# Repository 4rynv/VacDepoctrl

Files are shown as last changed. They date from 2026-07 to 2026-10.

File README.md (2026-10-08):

# VacDepoctrl — Vacuum Deposition Controller

A Raspberry Pi-based vacuum process controller. The current process is DC magnetron sputter deposition — chamber pump-down, argon gas flow, plasma ignition, and sputtering via a live Tkinter GUI with scrolling sensor graphs and a hardware-interlocked state machine. A thermal evaporation mode is planned as a second process on the same rig control stack.

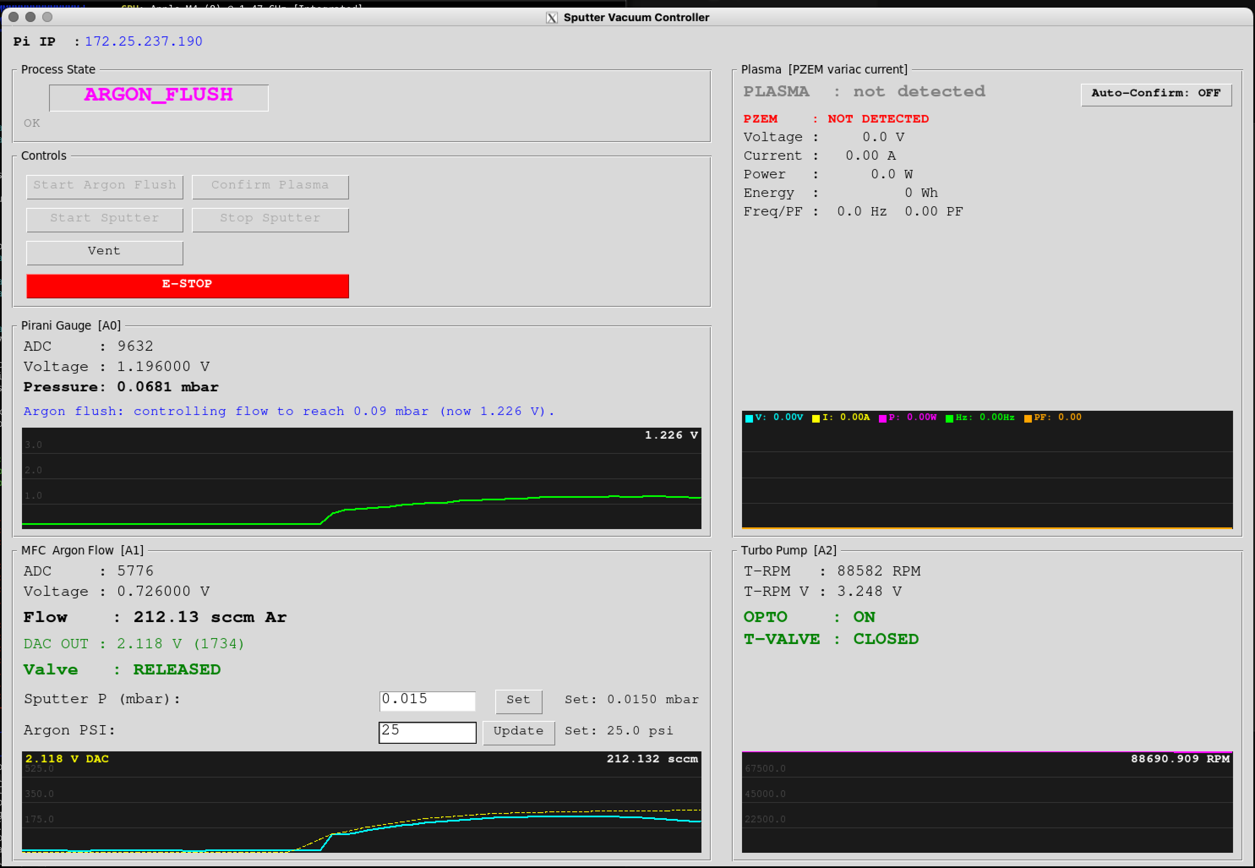
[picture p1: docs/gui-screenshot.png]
VacDepoctrl GUI


---

## Table of Contents

- [Hardware Overview](#hardware-overview)
- [Software Architecture](#software-architecture)
- [File Structure](#file-structure)
- [State Machine](#state-machine)
- [Pressure Reference](#pressure-reference)
- [Installation](#installation)
- [Running](#running)
- [Remote GUI Access](#remote-gui-access)
- [Web Dashboard](#web-dashboard)
- [Simulation Mode](#simulation-mode)
- [Configuration](#configuration)
- [GUI Guide](#gui-guide)
- [Known Limitations](#known-limitations)
- [Roadmap](#roadmap)

---

## Hardware Overview

| Component | Model | Interface | Notes |
|---|---|---|---|
| Microcontroller | Raspberry Pi 5 (BCM GPIO) | — | Host for all control logic |
| Pirani gauge | ACE Instruments DHPG-015 | Analog 0–10V | Divided to 0–3.3V before ADC (ratio 0.33) |
| ADC | ADS1115 | **I2C bus 1** @ 0x48 | Pirani on A0 (divided), MFC feedback on A1 (divided), turbo RPM tach on A2 |
| MFC | MKS 1179A | Analog 0–5V setpoint | 0–700 sccm Argon |
| DAC | MCP4725 | **I2C bus 1** @ 0x60 | Level-shifted to the MFC's full 0–5V setpoint range — see below |
| DAC buffer | LM358P op-amp | Analog | Buffers + level-shifts the DAC output up to 0–5V; DAC alone cannot drive the MFC setpoint input |
| Turbo enable | Opto-isolator (4N35) | GPIO 17 (BCM, phys 11) | Marginal — needs BC547 output buffer, see below |
| MFC valve close | Emergency shut | GPIO 27 (BCM, phys 13) | Pulls MFC valve closed on demand |
| Turbo inlet valve | Relay via BC547 | **GPIO 22 (BCM, phys 15)** | HIGH = valve OPEN, LOW = valve CLOSED (relay NC contact) |
| Energy meter | PZEM-004T-100A | Modbus-RTU over CP2102 USB-TTL, `/dev/ttyUSB0` | AC voltage/current/power on the variac output; plasma-ignition sensing. **Optional at startup** — see below |

### Raspberry Pi pin connections

[Full 40-pin header and device wiring diagram](docs/pinout.md)

| Function | BCM GPIO | Physical header pin | Connection |
|---|---|---|---|
| I2C1 SDA | GPIO2 | **3** | ADS1115 SDA + MCP4725 SDA |
| I2C1 SCL | GPIO3 | **5** | ADS1115 SCL + MCP4725 SCL |
| Signal ground | — | **6** (or another GND) | ADC/DAC signal ground |
| Turbo enable | GPIO17 | **11** | Opto-isolator input circuit |
| MFC emergency close | GPIO27 | **13** | Existing MFC valve-close interface |
| Turbo inlet valve | GPIO22 | **15** | BC547 relay-driver input |

GPIO23/24 (physical pins 16/18) are no longer the I2C connection.

### I2C: Hardware Bus 1 on GPIO 2/3

The Pi 5 uses hardware I2C1 at 100 kHz. Configure `/boot/firmware/config.txt`:

```ini
dtparam=i2c_arm=on
dtparam=i2c_arm_baudrate=100000
```

| Signal | BCM | Physical pin |
|---|---|---|
| SDA | GPIO 2 | 3 |
| SCL | GPIO 3 | 5 |
| GND | Ground | 6 |

Connect both ADS1115 and MCP4725 to this bus; keep pull-ups at 3.3 V.
Power down before moving SDA/SCL from the previous GPIO23/24 wiring.
The code uses `ExtendedI2C(I2C_BUS_NUMBER)` with `I2C_BUS_NUMBER = 1`.
The older software-bus setup was a workaround for reported damaged GPIO2/3
on a previous setup; this configuration assumes functioning GPIO2/3.
Reboot after changing boot configuration; the operator performs device checks
and the first controller launch with equipment in a safe condition.

### Voltage Divider (Pirani Output)

The DHPG-015 outputs 0–10V. A 3-resistor voltage divider scales this to 0–3.3V for the ADS1115 (divider ratio 0.33). All pressure thresholds in `config.py` are expressed in post-divider (ADC-side) volts. The full manufacturer calibration table lives in `hardware/datasheets/Di-Hi-Pr-Pirani output voltage.pdf` and is transcribed as `_PIRANI_CAL` in `main.py`.

### DAC Output Buffer + Level Shifter (LM358P)

The MCP4725 cannot source enough current to drive the MFC setpoint input directly — above ~1.25V the output voltage collapses under load even though it reads correctly when unloaded. An LM358P stage buffers the DAC output and shifts it up to the MFC's full 0–5V setpoint range before it reaches the MFC (`ARGON_DAC_VREF = 5.0` in `config.py` reflects this — commanded flow covers the full 0–`MFC_FULL_SCALE` range, not a fraction of it):

```
DAC OUT ──────────────┬──── LM358 IN+ (pin 3)
                       │
                  (feedback) IN- (pin 2) ──── OUT (pin 1) ──── MFC setpoint
LM358 VCC (pin 8) ── Pi 5V
LM358 GND (pin 4) ── GND
```

Power the op-amp from the Pi's **5V** rail, not 3.3V. The diagram above shows the original current-buffer wiring; the gain-setting feedback network that shifts the output up to 0–5V isn't captured in this ASCII diagram.

### Turbo Inlet Valve (GPIO 22 → BC547 → Relay → Solenoid)

The turbo inlet solenoid valve (~50 mA @ 25–26 V) is switched by a relay, driven by a BC547:

```
GPIO22 ──470Ω── base   BC547   collector ── relay coil ── +5V
                          emitter ── GND         ▲
                                          1N4007 across coil
                                          (band toward +5V)

Valve circuit ── relay COM + NC contacts (isolated from the Pi)
```

- Valve is wired through the relay's **NC (normally closed)** contact: relay released = valve circuit shorted = **valve CLOSED**; relay energized = **valve OPEN**.
- Logic (in `_poll()`, `turbo_valve_step()`): valve held CLOSED at all times; **latched OPEN** during **VENTING** once turbo pump RPM (tach on ADC A2, see [Turbo Pump RPM](#turbo-pump-rpm-adc-a2)) sustains `TURBO_VALVE_CONFIRM_SAMPLES` consecutive reads at or below `TURBO_VALVE_OPEN_RPM_MAX` (35000 RPM); re-closed automatically on leaving VENTING. The debounce prevents a single corrupted I2C read from opening the valve; the latch prevents relay chatter once open. Driven by rotor speed directly rather than inferring it from chamber pressure — the earlier pressure-based gate (`TURBO_VALVE_OPEN_MBAR`) has been replaced.
- Fail-safe: if the Pi crashes or loses power, the relay releases and the valve **fails closed** — the safe direction for the turbo inlet.
- GUI shows live actuation state (`T-VALVE : CLOSED` / `OPEN (venting)`).

### Turbo Pump RPM (ADC A2)

- Tach/speed output, 0–3.3V linear = 0–90000 RPM (`TURBO_RPM_VOLTAGE_FULL_SCALE`, `TURBO_RPM_FULL_SCALE`), read by `TurboRPMController` (`turbo_rpm.py`) every poll tick regardless of state.
- Displayed in its own **Turbo Pump** panel (`T-RPM`, `T-RPM V`, a scrolling RPM graph, plus `OPTO` and `T-VALVE` state — both turbo-side actuators, moved here from the Pirani panel) — below the Plasma panel, beside the Pirani/MFC panels.
- During **VENTING**, once RPM drops to/below `VENTING_PUMP_OFF_PROMPT_RPM` (2000), the Pirani panel's status message turns orange and prompts the operator to turn off the primary/roughing pump — an early, informational cue, not a gate. The actual gate on completing the vent is separate — see [Vent Completion Confirmation](#vent-completion-confirmation) below.
- Feeds the turbo inlet valve interlock above and the cross-sensor checks below.

### Vent Completion Confirmation

Reaching atmospheric pressure during VENTING does **not** by itself complete the vent. Earlier, `sm.update()` transitioned `VENTING → IDLE` purely from Pirani voltage — but the turbo inlet valve closes the instant the state leaves VENTING (`turbo_valve_step()`), so that auto-transition could reclose the valve before the operator had any real chance to react to the "turn off the primary pump" cue above, let alone actually do it.

`VENTING → IDLE` is now owned exclusively by `_poll()` (the same ownership pattern as `ARGON_FLUSH → PLASMA_IGNITING`), gated by `vent_complete_ready()`: **both** atmospheric pressure **and** an explicit operator click are required.

- Once Pirani reaches `VENTING_COMPLETE_VOLTAGE` during VENTING, `_state["vent_complete_pending"]` latches True — the Pirani panel's status message turns red ("Atmosphere reached — turn OFF the primary/roughing pump, then click Confirm Pump Off") and a **Confirm Pump Off** button appears in Controls (hidden otherwise, same show/hide pattern as Clear Fault).
- Clicking it sets `_state["vent_complete_confirmed"]`; `_poll()` picks this up on its next tick and, if pressure is still at/above atmosphere, transitions to IDLE — closing the turbo inlet valve as part of the normal VENTING-exit path.
- Both flags reset on entering IDLE or VENTING (`handle_hardware_interlocks()`), so a stale confirmation from a previous cycle can never auto-complete the next one.

### Energy Meter (PZEM-004T-100A, plasma ignition sensing)

Reads AC voltage/current/power/energy/frequency/power-factor on the sputtering supply's **variac output** and uses the current-draw step when the discharge strikes to detect plasma ignition. Talks Modbus-RTU over a CP2102 USB-TTL adapter plugged into the Pi's USB port (`pzem_meter.py`) — a completely separate transport from the ADS1115/MCP4725 I2C bus above.

> [!warning] Mains AC hazard
> The PZEM's voltage-sense terminals and current-transformer (CT) clamp are on **live mains-derived AC**, not the Pi's low-voltage side. Work de-energized (variac and upstream breaker off), verify with a meter before touching any terminal, don't work alone, and don't exceed the CT's 100A rating. The PZEM's internal isolation protects the TTL/USB side from the AC side *once wired correctly* — it does not protect you while wiring it.

#### Wiring

**AC side (mains, de-energized while wiring):**

- Connect the PZEM's **L / N voltage-sense terminals directly across the variac's OUTPUT** (not its input) — the two wires feeding whatever the variac drives (typically an HV/isolation transformer feeding the sputtering cathode supply).
- Clamp the **split-core CT around the same variac output's live (L) conductor** — do not clamp both L and N together (their fields cancel and it reads ~0A), and do not clamp the input side.
- Wiring the CT and voltage sense to the *same* side (output) is required for the power reading to mean anything — the PZEM computes P = V × I × PF locally, so V and I must reflect the same node.
- This placement means voltage/current/power all read what's actually delivered to the sputtering supply, independent of the variac's own tap position — exactly the load signature that changes when the discharge strikes (impedance drop → current step).

**TTL side (isolated, low-voltage, safe to wire live):**

| PZEM TTL pin | CP2102 pin | Notes |
|---|---|---|
| 5V  | 5V  | PZEM-004T v3.0's TTL interface requires 5V — verify the CP2102's voltage-select jumper (if it has one) is set to 5V, not 3.3V |
| GND | GND | Common ground |
| TXD | RXD | Cross — PZEM transmits into the adapter's receive pin |
| RXD | TXD | Cross — PZEM receives from the adapter's transmit pin |

Plug the CP2102 into any Pi USB port. It enumerates as `/dev/ttyUSB0` (check with `ls /dev/ttyUSB*`; use a `/dev/serial/by-id/...` symlink instead if more than one USB-serial device is ever attached). The Pi user needs the `dialout` group to access it without root:

```bash
sudo usermod -a -G dialout $USER
# log out and back in for the group change to take effect
```

#### Protocol

Modbus-RTU, 9600 baud 8N1, factory-default slave address `0xF8`. `pzem_meter.py` hand-rolls the request framing and CRC16 (matching how `mfc_control.py` hand-rolls the MCP4725 I2C write) rather than pulling in a general Modbus library — reads input registers 0x0000–0x0009 (voltage, current, power, energy, frequency, power factor, alarm) every poll tick.

**Optional hardware, unlike the ADS1115/MCP4725 checked in `_startup_self_test()`:** this sensor may not be wired up yet. `PZEMController.read()` never raises — if the serial port can't be opened or the meter doesn't respond, it returns `ready=False` and a zeroed reading. `main.py`'s two PZEM cross-sensor checks (below) only evaluate `if e["ready"]`, so nothing they do can fire until the meter is actually installed and responding — deploying this code cannot regress a rig that doesn't have the PZEM wired yet.

#### Plasma Detection

`plasma_detect_step()` applies the same debounced ON/OFF hysteresis pattern as the turbo enable opto (`TURBOOPTO_ON/OFF_THRESHOLD`) to the PZEM's current reading: `PZEM_PLASMA_CURRENT_ON_A` (default 1.0A, **unvalidated placeholder**) held for `PZEM_PLASMA_CONFIRM_SAMPLES` (3) consecutive ticks latches `plasma_detected` True; it clears immediately below `PZEM_PLASMA_CURRENT_OFF_A` (0.6A). Like every other cross-sensor threshold in this repo, these must be bench-measured against the real supply's no-load vs. struck-plasma current before they mean anything.

`plasma_detected` drives the **Plasma** GUI panel (replacing the old placeholder) and the `PLASMA_IGNITING → SPUTTER_READY` confirmation, which now has three paths:

| Path | Trigger | Default |
|---|---|---|
| Manual | Operator clicks **Confirm Plasma** | Always available |
| Hybrid cue | Confirm Plasma button highlights green once `plasma_detected` is True during `PLASMA_IGNITING` — operator still clicks | Always on |
| Auto-confirm | Operator arms the **Auto-Confirm** toggle in the Plasma panel; while armed, a confirmed detection advances the state machine the same way a manual click would, via the same `_complete_plasma_confirmation()` path | **Off by default** |

Auto-confirm is an explicit operator opt-in, not the default, because `PZEM_PLASMA_CURRENT_ON_A` is unvalidated — the same reasoning as every other "unvalidated until confirmed on the bench" threshold in `config.py`. `PLASMA_IGNITING`'s own `PLASMA_IGNITION_TIMEOUT` abort-to-READY path is unchanged and still the fallback if neither manual nor auto-confirm fires.

#### Bring-up notes / troubleshooting

- **Board-specific terminal layout, not the generic datasheet.** On Aryan's board, the AC-side 4-terminal block is L / N (voltage sense, across variac output) and two CT-lead terminals — but the *position* of these on the physical block didn't match the generic PZEM-004T datasheet. The L line initially went to the board's 10A direct-pass-through terminal position instead of the 100A/CT-clamp position; moving it to the correct terminal (found via the board's own silkscreen, not the datasheet) fixed it. **Always read your specific board's silkscreen, not a generic online diagram.**
- **The PZEM's measurement MCU is powered from the AC L/N line itself**, not the TTL 5V header. Symptom if you wire TTL first and haven't energized L/N yet: CP2102 TX blinks (host is sending fine), PZEM never replies — looks like a dead unit but is just unpowered. Resolves once L/N is actually connected to live AC.
- **A struck-but-undetected plasma likely means the CT isn't sensing the load, not a threshold-tuning problem.** Hit 2026-07-12: operator visually confirmed plasma and clicked Confirm Plasma, `PLASMA_IGNITING → SPUTTER_READY` succeeded, then `pzem_plasma_absent_check()` force-shut-down 5s later with the PZEM reporting **0.00 A** the entire time. A true zero (not "some current below 1.0A") points at the sensor path, not calibration — most likely the CT clamp isn't actually installed on the load line yet (this repo's CT bring-up was still pending a bench test on the real variac-output load as of the prior session), or is clamped over both L and N together (fields cancel to ~0A), rather than L alone.
- **If real current draw is small relative to the CT's 100A rating, wind multiple turns of the live conductor through the clamp before closing it.** A CT senses ampere-*turns*, so *N* turns gives `N × I_actual` on the reading — useful because a 100A-rated core sensing a sub-1A sputtering load sits at the very bottom of its response curve, where accuracy/noise floor issues are common. Divide the reported current/power by *N* in software to recover the true value, or (simpler, since only the comparison matters) scale `PZEM_PLASMA_CURRENT_ON_A`/`_OFF_A` by *N* instead. Sanity-check the real current independently first (a separate clamp meter, or the sputtering supply's own front-panel readout) before deciding how many turns to use.

### Cross-Sensor Consistency Checks

Every threshold elsewhere in this doc compares one sensor to one fixed value. These instead compare two live readings to each other — catching a case where each reading is individually "in range" but the two together don't make physical sense. All feed the **global safety gate** below: a sustained flag forces a full hardware cutoff, not just a status message. Grace periods are placeholder defaults (favor fewer false positives over noise from normal settling time) — tune once measured against real spin-up/response/settling behavior on the bench. Because a false positive forces a real shutdown, treat these as unvalidated until confirmed on the bench.

| Check | Compares | Flags when | Config |
|---|---|---|---|
| `turbo_spinup_check()` | Turbo enable opto (GPIO 17) vs turbo RPM (ADC A2) | Opto commanding the turbo on for `TURBO_SPINUP_GRACE_SECONDS` (60s) while RPM stays below `TURBO_RPM_STALL_THRESHOLD` (10000) — turbo/RPM-sensor/wiring fault, or the turbo never spun up at all | `config.py` |
| `turbo_rpm_drop_check()` | Same opto/RPM pair, but tracks a confirmed-healthy peak | RPM has exceeded `TURBO_RPM_STALL_THRESHOLD` at least once (confirmed healthy spin), then drops back below it for `TURBO_RPM_DROP_GRACE_SECONDS` (10s) while opto is still on — a running turbo failing/degrading, distinct from "never spun up" | `config.py` |
| `mfc_flow_check()` | Commanded flow (DAC/`flow_target`) vs measured flow (A1 feedback) | Commanded ≥ `MFC_FLOW_MIN_COMMANDED_SCCM` (20) but measured stays below `MFC_FLOW_RESPONSE_FRACTION` (0.2×) of commanded for `MFC_FLOW_GRACE_SECONDS` (5s) — MFC not responding, dead unit, or empty gas supply | `config.py` |
| `dac_saturation_flow_check()` | DAC output voltage vs measured flow | DAC pegged within `DAC_SATURATION_MARGIN_V` (0.1V) of `ARGON_DAC_VREF` while measured flow stays below `DAC_SATURATION_FLOW_FRACTION` (0.5×) of `MFC_FULL_SCALE`, for `DAC_SATURATION_GRACE_SECONDS` (10s) — the PID has given up on proportional correction and is commanding max output with nothing coming back: stuck valve, blocked line, or empty supply. A stronger signal than `mfc_flow_check` alone | `config.py` |
| `pressure_convergence_check()` | Current Pirani voltage vs the active PID target (flush/sputter) | `\|current - target\|` exceeds `PRESSURE_CONVERGENCE_TOLERANCE_V` (0.3V) for `PRESSURE_CONVERGENCE_GRACE_SECONDS` (90s) despite the control loop running — leak, stuck valve, or MFC fault. Raised from 20s after a bench run showed a legitimate large setpoint step (e.g. PLASMA_IGNITING → SPUTTER_READY) needs longer than that to converge given the deliberately gentle PID tuning | `config.py` |
| `pzem_plasma_absent_check()` | Process state (SPUTTER_READY/SPUTTERING only) vs PZEM `plasma_detected` | In SPUTTER_READY or SPUTTERING — both assume plasma is already lit — with no PZEM-confirmed current draw for `PZEM_PLASMA_ABSENT_GRACE_SECONDS` (5s): an arc dropout or the plasma extinguishing mid-run. PLASMA_IGNITING is deliberately excluded (`PLASMA_IGNITION_TIMEOUT` already owns "never struck"). Only evaluated once the PZEM is `ready` — see Energy Meter section above | `config.py` |
| `pzem_power_unexpected_check()` | Process state (everywhere except PLASMA_IGNITING/SPUTTER_READY/SPUTTERING) vs PZEM `plasma_detected` | Plasma-level current draw while nowhere near attempting ignition (IDLE/PUMP_DOWN/READY/ARGON_FLUSH/VENTING) for `PZEM_POWER_UNEXPECTED_GRACE_SECONDS` (5s) — stuck relay, live supply, or wiring fault. Only evaluated once the PZEM is `ready` | `config.py` |

All are pure functions (`main.py`, next to `turbo_valve_step()`) — no I/O, no wall-clock access internally (the current timestamp is passed in), so they're tested directly like the calibration/valve logic.

### Global Safety Gate

Everything above this point in the doc is a *local* mechanism: a specific check for a specific failure, conditioned on which state you're in. The global gate is different — evaluated every poll tick **regardless of current state**, and any single condition tripping it forces the exact same full cutoff: turbo valve closed (direct GPIO write), MFC flow/valve/opto off, state forced to IDLE (`sm.emergency_stop()`), **and the trip latches** (see below).

| Condition | Detects | Config |
|---|---|---|
| Sustained cross-sensor flag | Any of the checks above, once their own grace period elapses | see table above |
| `sensor_range_check()` | Any ADC-derived voltage (Pirani, MFC feedback, turbo tach) outside `SANE_VOLTAGE_MIN`/`SANE_VOLTAGE_MAX` for `SENSOR_RANGE_CONFIRM_SAMPLES` (5) consecutive ticks — disconnected, shorted, or miswired sensor, not a legitimate reading at any pressure/flow/speed. Suppressed for `STARTUP_GRACE_SECONDS` (5s) after the poll loop starts — real analog settling transients (MFC feedback observed at -0.15 to -0.23V for a few seconds after power-on) tripped this otherwise | `config.py` |
| Consecutive poll-loop exceptions | `CONSECUTIVE_EXCEPTION_LIMIT` (5) ticks in a row raise — occasional I2C/EMI glitches are tolerated (as before), but this many in a row is a real fault, not noise. Also suppressed during `STARTUP_GRACE_SECONDS` | `config.py` |
| Heartbeat / watchdog | The GUI thread (`_refresh()`) checks `_state["last_tick"]`; if the poll loop hasn't updated it within `HEARTBEAT_TIMEOUT_SECONDS` (2.0s), the poll thread is presumed stalled/hung. Checked from the GUI thread specifically — a hung poll thread can't detect its own hang | `config.py` |

All of this routes through `_force_safe_shutdown(reason)` (`main.py`) — safe to call every tick for as long as a condition persists (GPIO/state-machine calls are idempotent; `_set_error()` de-dupes the repeated log line rather than spamming it). `handle_hardware_interlocks()`'s own mfc/pirani cutoffs are already exception-safe (`SputterStateMachine` catches callback errors internally), so the only extra guarding needed is around the direct turbo-valve GPIO write, in case the poll thread hung mid-I2C-transaction.

**The trip latches — a bench run found why this matters.** `emergency_stop()` alone forces IDLE, but IDLE's own auto-resume-to-PUMP_DOWN logic (`_poll()`) will immediately re-enter PUMP_DOWN if pressure is already low (e.g. an external roughing pump already has the chamber down) — silently undoing the shutdown within one tick, with the process continuing as if nothing happened. `_force_safe_shutdown()` now sets `_state["safety_tripped"]`, which blocks that auto-resume and shows a red banner + "Clear Fault" button in the Process State panel, plus a one-time modal alert. The IDLE branch checks this flag before its auto-transition. Clearing does **not** reset the underlying check's own "since" timer — if the root cause is still present, it re-trips immediately on the next tick. That's intentional: acknowledging a fault without fixing it must not let the process quietly continue.

### Startup Self-Test

Runs once before the poll thread starts (`_startup_self_test()`, `main.py`): re-validates config invariants at runtime (`config_sanity_failures()` — same checks as `TestConfigSanity`, but live, so a bad future edit to `config.py` is caught before the app runs with a broken safety threshold; this is exactly the class of bug that shipped once, `VENTING_COMPLETE_VOLTAGE` at ~5 mbar instead of near-atmosphere), and confirms the ADS1115 and MCP4725 DAC actually ACK on the I2C bus. Any failure prints to console and exits — no GUI exists yet at this point in startup.

### Persistent Event Log

Every operator-visible error/warning and every state transition is appended to `sputter_ctrl.log` (next to `main.py`, `EVENT_LOG_FILENAME` in config) via `_log_event()` — the GUI status bar only shows the latest message and auto-expires it after `ERROR_DISPLAY_SECONDS`, so this is the only place an incident can be reconstructed after the fact. `_set_error()` is the single choke point every error message goes through (writes `_state["error"]` and logs, de-duping repeats); `handle_hardware_interlocks()` logs every transition unconditionally, regardless of which state it's entering.

Do **not** drive relay coils or solenoids from a 4N35 directly — see the hard-won rule below.

### Opto/Load Rule of Thumb (learned the expensive way)

A 4N35's usable output current is roughly `CTR (~100%) × LED current (~10 mA max from a GPIO)` ≈ **10 mA**. Asked for more, it goes linear and drops the supply across itself (looks like a mystery series resistor). Loads measured on this rig:

| Load | Draw | 4N35 alone? |
|---|---|---|
| Turbo enable input | ~15–30 mA | **No** — needs BC547 buffer (pending) |
| Relay coil (5V) | ~60 mA | No — driven by BC547 directly, opto not needed (relay contacts provide the isolation) |
| Inlet solenoid | ~50 mA @ 26V | No — relay contacts switch it |

The turbo enable opto (GPIO 17) currently only works with excess LED drive; the proper fix is a BC547 buffer on its output (opto pin 5 → enable+, pin 4 → BC547 base, 10 kΩ base–emitter, BC547 C/E across the enable terminals). Flyback diodes go **in parallel across coils** (reverse-biased), never in series.

---

## Software Architecture

```
main.py
├── Hardware init (GPIO, ExtendedI2C bus 1, ADS1115)
├── Shared state dict (thread-safe, _lock)
├── Polling thread (_poll) — runs every POLLING_INTERVAL (0.2s)
│   ├── Reads Pirani + MFC + turbo RPM (A2) + PZEM (variac current) sensors
│   ├── Drives MFC pressure PID loop
│   ├── Drives turbo inlet valve latch (GPIO 22), gated on turbo RPM (not pressure)
│   ├── Debounced plasma_detect_step() from PZEM current -> plasma_detected
│   ├── Auto-confirms PLASMA_IGNITING -> SPUTTER_READY if the operator has
│   │   armed Auto-Confirm and plasma_detected is True
│   ├── Calls sm.update() for auto-transitions
│   ├── Converts Pirani voltage <-> mbar via log-linear calibration table
│   ├── End-of-tick safety cutoff re-assert (E-STOP race guard)
│   └── Updates shared state dict
├── Tkinter GUI (main thread)
│   ├── _refresh() — runs every GUI_REFRESH_INTERVAL (200ms) via root.after()
│   ├── Scrolling graphs (ScrollingGraph)
│   ├── Live pressure readout in mbar (adc_voltage_to_mbar)
│   ├── Manual set-point entry fields (sputter target mbar, argon PSI)
│   ├── Error display with ERROR_DISPLAY_SECONDS auto-expiry
│   └── Button callbacks → shared _try_*() operator commands
├── Web dashboard server (daemon threads — web_ui.py, see Web Dashboard)
│   ├── GET /events — SSE stream of _state snapshots to each browser
│   └── POST /command — dispatches the SAME _try_*() operator commands
└── Hardware interlock callback
    └── handle_hardware_interlocks() — fires on every state transition
```

The polling thread and GUI thread never share objects directly — all data passes through `_state` dict protected by `_lock`. On window close, `_stop_event` is set and the polling thread is **joined** (2 s timeout) before hardware shutdown and `GPIO.cleanup()`.

**E-STOP race guard:** the poll loop reads the state once per tick; if an E-STOP/vent transition lands mid-tick, the interlock callback's cutoff could be overwritten by in-flight `valve_release()`/`set_flow()` calls. The poll loop therefore re-asserts the full safety cutoff at the end of any tick in which the state machine moved to IDLE/VENTING — the cutoff is always the last hardware write of the tick.

**Error handling:** errors are no longer cleared by the polling loop each tick. They persist in the status bar for `ERROR_DISPLAY_SECONDS` (10 s) and then auto-expire, so both operator-guard messages and the plasma-timeout message are actually readable.

---

## File Structure

```
VacDepoctrl/
├── main.py            — Entry point: GUI, polling thread, hardware init, cal table
├── config.py          — All constants, thresholds, and pin assignments
├── state_machine.py   — SputterStateMachine class (future: per-process state machines)
├── drivers/           — one class per hardware device
│   ├── mfc_control.py — MFCController class (DAC, valve, PID loop)
│   ├── pirani.py      — PiraniController class (ADC, turbo enable opto)
│   ├── turbo_rpm.py   — TurboRPMController class (ADC A2 tach → RPM)
│   └── pzem_meter.py  — PZEMController class (PZEM-004T-100A, Modbus-RTU over USB-TTL)
├── ui/
│   ├── graph.py       — ScrollingGraph class (pure Tkinter, no matplotlib; single/dual/multi-series)
│   ├── web_ui.py      — browser dashboard server (stdlib HTTP + SSE), parallel to the Tkinter GUI
│   └── web/
│       └── index.html — the dashboard page (self-contained: inline CSS/JS, no CDN)
├── sim/
│   └── sim_hardware.py — ChamberSim + fake hardware modules for SPUTTER_SIM=1 (Simulation Mode)
├── hardware/
│   ├── Raspi_HAT/     — KiCad project for the custom Raspberry Pi HAT (schematic/PCB/BOM)
│   └── datasheets/    — Pirani gauge output-voltage table PDF
├── docs/              — GUI screenshot and other README assets
├── assets/            — desktop/app icon source (app-icon*.png, AppIcon.icns)
├── scripts/
│   ├── setup.sh       — venv + dependency installer, also installs the desktop launcher
│   ├── VacDepoctrl.desktop       — desktop launcher icon (installed by setup.sh; see Installation)
│   ├── setup_remote_gui_macos.sh — one-time XQuartz setup, see Remote GUI Access
│   └── build_mac_launchers.sh    — builds the VacDep Remote.app / VacDep Simulation.app Desktop icons
└── tests/
    ├── adc_test.py         — ADS1115 read loop (bus 1)
    ├── dac_test.py         — MCP4725 sweep + readback (bus 1)
    ├── opto_test.py        — GPIO 17 turbo enable opto toggle
    ├── turbo_valve_test.py — GPIO 22 relay/valve toggle
    ├── pzem_test.py        — PZEM-004T-100A live reading loop (USB-TTL)
    └── unit/               — hardware-free unit suite (fakes.py + test_all.py)
```

---

## State Machine

### States and Transitions

```
                    pressure rises
         ┌─────────────────────────────┐
         ▼                             │
       IDLE ──(pressure drops)──► PUMP_DOWN ──(vacuum reached + opto)──► READY
         ▲                             │                                     │
         │                    pressure rises                        [Start Argon Flush]
         │                             │                                     ▼
         └─────────────────────────────┘                            ARGON_FLUSH
                                                                         │
                                                              (0.09 mbar reached)
                                                                         ▼
                                                               PLASMA_IGNITING
                                                              │              │
                                                   [Confirm Plasma]    (2 min timeout)
                                                              │              │
                                                              ▼              ▼
                                                        SPUTTER_READY     READY
                                                              │
                                                       [Start Sputter]
                                                              ▼
                                                          SPUTTERING
                                                              │
                                                       [Stop Sputter]
                                                              ▼
                                                          VENTING
                                                              │
                                                (3.0V atmosphere) + [Confirm Pump Off]
                                                              ▼
                                                            IDLE

         Any state ──[Vent]──► VENTING ──(3.0V Pirani + Confirm Pump Off)──► IDLE
         Any state ──[E-STOP]──► IDLE (immediate hardware cutoff, latched — Clear Fault to resume)
```

### Automatic Transitions

| From | To | Condition | Where |
|---|---|---|---|
| `IDLE` | `PUMP_DOWN` | Pirani voltage ≤ 2.71V (10 mbar) | `_poll()` |
| `PUMP_DOWN` | `IDLE` | Pirani voltage ≥ 2.71V (pump failure/leak) | `_poll()` + `sm.update()` |
| `PUMP_DOWN` | `READY` | Voltage ≤ 0.3V AND opto enabled | `sm.update()` |
| `READY` | `PUMP_DOWN` | Pirani voltage ≥ 2.71V (pressure degraded) | `sm.update()` |
| `ARGON_FLUSH` | `PLASMA_IGNITING` | Voltage ≥ 1.287V (0.09 mbar) | **`_poll()` only** — sole owner: arms the ignition timeout and fires `_ignite_plasma()` |
| `PLASMA_IGNITING` | `READY` | 120s timeout, no plasma confirmation | `_poll()` |
| `PLASMA_IGNITING` | `SPUTTER_READY` | PZEM confirms plasma-level current draw, **only if the operator has armed Auto-Confirm** | `_poll()` — see [Energy Meter](#energy-meter-pzem-004t-100a-plasma-ignition-sensing) |
| `VENTING` | `IDLE` | Pirani voltage ≥ 3.0V (near-atmosphere) **AND** operator has clicked Confirm Pump Off | **`_poll()` only** — see [Vent Completion Confirmation](#vent-completion-confirmation) |

`PLASMA_IGNITING → SPUTTER_READY` is **operator-driven by default** (Confirm Plasma button, highlighted once the PZEM confirms detection) with an explicit opt-in **Auto-Confirm** toggle for the sensor-driven path — see the Energy Meter section for why auto-confirm defaults off. `VENTING → IDLE` similarly requires an explicit operator click regardless of pressure — there is no auto-confirm option for this one, since it's gating a real physical action (turning off the primary pump), not just a detection threshold.

### Manual Transitions (Operator Buttons)

| Button | Transition | Guard |
|---|---|---|
| Start Argon Flush | `READY → ARGON_FLUSH` | Argon inlet ≥ 15 psi |
| Confirm Plasma | `PLASMA_IGNITING → SPUTTER_READY` | None |
| Start Sputter | `SPUTTER_READY → SPUTTERING` | Argon inlet ≥ 15 psi |
| Stop Sputter | `SPUTTERING → VENTING` | None |
| Vent | `PUMP_DOWN`, `READY`, `ARGON_FLUSH`, `PLASMA_IGNITING`, `SPUTTER_READY`, `SPUTTERING` → `VENTING` | None — `PUMP_DOWN` added 2026-07-12 (previously only `IDLE→PUMP_DOWN→IDLE` was reachable from PUMP_DOWN; vent is now available mid-pump-down too) |
| Confirm Pump Off | `VENTING → IDLE` | Only appears once atmosphere is reached; see [Vent Completion Confirmation](#vent-completion-confirmation) |
| E-STOP | Any → `IDLE` | None — immediate. Routes through `_force_safe_shutdown()`: closes the turbo valve by direct GPIO write (no dependency on the poll thread being alive) and **latches** — Clear Fault required to resume, like a real EMO reset |

### Hardware Interlock Callback

`handle_hardware_interlocks()` fires synchronously on every state transition:

- **→ IDLE or VENTING**: `mfc.set_flow(0)`, `mfc.valve_close()`, `pirani.set_opto(False)`, and resets `plasma_ignition_start` / `plasma_ignition_triggered` so the next flush cycle starts clean (a stale flag previously could leave PLASMA_IGNITING with no armed timeout)
- **→ PUMP_DOWN**: `pirani.set_opto(False)` — resets opto for next pump-down cycle

During VENTING the poll loop additionally holds the MFC valve **closed** every tick (venting is done with the turbo inlet valve, not through the MFC).

---

## Pressure Reference

All voltages are post-divider (ADC input, ×0.33 from raw gauge output). Conversion between Pirani voltage and mbar uses **log-linear interpolation** against the full manufacturer calibration table (`_PIRANI_CAL` in `main.py`, source PDF in `hardware/datasheets/`): linear in voltage, logarithmic in pressure, matching the gauge's thermal-conductivity response. Both directions are implemented (`mbar_to_adc_voltage`, `adc_voltage_to_mbar`) and round-trip to machine precision at all 51 table points.

| Pressure (mbar) | Raw gauge (V) | ADC input (V) | Significance |
|---|---|---|---|
| 999 | 10.00 | 3.30 | Atmosphere (ADC saturated) |
| ~213 | — | 3.0 | `VENTING_COMPLETE_VOLTAGE` — VENTING → IDLE (safety margin below the 3.30V atmosphere point so the transition reliably fires) |
| 10 | 8.20 | 2.706 | `IDLE_PRESSURE_MAX_VOLTAGE` — pump-down gate |
| 0.09 | 3.90 | 1.287 | `ARGON_FLUSH_TARGET_VOLTAGE` — plasma ignition pressure |
| ~0.183 | 4.24 | 1.4 | Turbo enable opto fires (PUMP_DOWN, transition-based; raised from 1.3V 2026-07-12) |
| ~0.0057 | 0.91 | 0.3 | `PUMP_DOWN_COMPLETE_VOLTAGE` — PUMP_DOWN → READY gate (raised from 0.2V 2026-07-12) |
| 0.007 | 1.10 | 0.363 | 0.007 mbar — default sputtering pressure |

The GUI displays live pressure in mbar (bold, under the voltage readout), computed via `adc_voltage_to_mbar()`; reads `ATM (>999 mbar)` at ADC saturation.

### Sputter Target Pressure (operator-settable)

An input field sets the SPUTTER_READY / SPUTTERING target pressure directly in mbar (default 0.007). Entered values are converted to an ADC voltage target via the calibration table before being passed to `pressure_control_step()`.

Validated at entry: must be `> 0` and `≤ SPUTTER_TARGET_MAX_MBAR` (0.05 mbar). Values above the cap are rejected with a warning dialog rather than silently accepted — this also catches an Argon PSI value (tens) fat-fingered into this field, since any such value is far above the cap. Similarly, the Argon PSI field rejects anything below `ARGON_PRESSURE_MIN_PSI` (15 psi) with a warning, catching a Sputter P mbar value entered in the wrong field.

### Turbo Enable Opto Logic (GPIO 17)

Transition-based, not level-based:

- Goes **HIGH** the first time Pirani voltage drops below **1.4V** during `PUMP_DOWN` (raised from 1.3V 2026-07-12)
- Once set, stays HIGH until any state transition resets it via the interlock callback
- This prevents opto chatter on noisy ADC readings near the threshold
- Separate from `TURBOOPTO_ON_THRESHOLD`/`TURBOOPTO_OFF_THRESHOLD` in `config.py` (ADC-count based, ~1.31V/~1.87V) — those drive `pirani.py`'s `auto_opto=True` hysteresis path used in READY/ARGON_FLUSH, a different code path from this PUMP_DOWN transition-based one. The two are not currently kept in sync; only the PUMP_DOWN threshold above was changed this session.

---

## Installation

### 1. Clone the Repository

```bash
ssh av@<pi-ip>
git clone https://github.com/<your-username>/VacDepoctrl.git ~/VacDepoctrl
cd ~/VacDepoctrl
```

### 2. Enable Hardware I2C

Wire physical pins 3/5 as described above. Enable these settings under `[all]`
in `/boot/firmware/config.txt`, removing any old `i2c-gpio` overlay:

```ini
dtparam=i2c_arm=on
dtparam=i2c_arm_baudrate=100000
```

The operator should reboot when safe, then verify `/dev/i2c-1` exists.
Hardware verification should find ADS1115 at 0x48 and MCP4725 at 0x60.
Do not launch the controller until the wiring and equipment are ready:
`main.py` configures outputs immediately and can automatically enter PUMP_DOWN.

### 3. Run the Setup Script

```bash
cd ~/VacDepoctrl
chmod +x scripts/setup.sh
./scripts/setup.sh
```

This installs `adafruit-blinka`, `adafruit-circuitpython-ads1x15`, `adafruit-extended-bus`, `rpi-lgpio` (providing the `RPi.GPIO` API), and `pyserial` into a venv at `~/VacDepoctrl/venv/`, adds a `source_vacdep` alias to `~/.bashrc`, and places a **VacDepoctrl** icon on the desktop (`VacDepoctrl.desktop`) — double-click it to launch `main.py` directly, no terminal needed. First launch may need a one-time "Allow Launching" confirmation (right-click the icon → Allow Launching) depending on the desktop environment's trust settings for new `.desktop` files.

```bash
source ~/.bashrc
source_vacdep
```

### 4. (Optional) Energy Meter Serial Permissions

If the PZEM-004T-100A / CP2102 is wired up (see [Energy Meter](#energy-meter-pzem-004t-100a-plasma-ignition-sensing)), add the Pi user to `dialout` so `main.py` can open `/dev/ttyUSB0` without root:

```bash
sudo usermod -a -G dialout $USER
# log out and back in for the group change to take effect
```

This step can be skipped entirely — the meter is optional hardware and `main.py` starts normally without it (see `pzem_meter.py`).

---

## Running

Must be run on the Pi with a display connected (HDMI or VNC), not over a plain SSH session.

```bash
source_vacdep
cd ~/VacDepoctrl
python main.py
```

> Note: use `python`, not `python3`, inside the activated venv on this setup.

To run over SSH with display forwarding:

```bash
ssh -X av@<pi-ip>
source_vacdep && cd ~/VacDepoctrl && python main.py
```

This renders the GUI on your own machine instead of the Pi's local display —
see [Remote GUI Access](#remote-gui-access) below for one-time setup and why
you'd want to.

Bench-test scripts (run these with `main.py` stopped — they fight over pins):

```bash
python tests/adc_test.py          # live ADC readings, both channels
python tests/dac_test.py          # DAC voltage staircase + register readback
python tests/opto_test.py         # GPIO 17 toggle every 5 s
python tests/turbo_valve_test.py  # GPIO 22 relay/valve toggle every 5 s
```

---

## Remote GUI Access

**Why**: Raspberry Pi OS Bookworm's default desktop uses a Wayland compositor
(`labwc`). On older/weaker boards that compositor can
alone consume most of the CPU just keeping the desktop alive — independent of
`main.py` — which shows up as system-wide lag, including the mouse cursor
itself stuttering. Tkinter also doesn't speak Wayland natively; on this
desktop it runs through an `Xwayland` compatibility shim that gets composited
by `labwc` anyway, adding a second layer of overhead on top.

SSH X11 forwarding (`ssh -X`) sidesteps all of that: `main.py` still runs
*on* the Pi (it has to — that's where the GPIO/I2C/PZEM-over-USB hardware
physically is), but the X11 *protocol* (drawing commands, not rendered
frames) is tunneled to an X server running on your own machine, which does
the actual rendering. None of the Pi's local compositor is involved. This is
optional — if you're on the Pi's physical HDMI display or VNC and it isn't
laggy for you, there's nothing to set up.

The Pi side needs no configuration — `sshd` already has `X11Forwarding yes`
and `xauth` installed. Every OS below needs its own X server to *receive*
the forwarded connection, since none of them speak X11 out of the box.

### macOS

```bash
./scripts/setup_remote_gui_macos.sh
```

Or manually:

```bash
brew install --cask xquartz
open -a XQuartz
```

Then from a **new** terminal (so it picks up XQuartz's environment):

```bash
ssh -X av@<pi-ip>
source_vacdep && cd ~/VacDepoctrl && python main.py
```

If the window doesn't appear, try `-Y` (trusted forwarding, fewer
restrictions) instead of `-X`. Still nothing? As a last resort:

```bash
defaults write org.macosforge.xquartz.X11 nolisten_tcp -bool false
```

then quit and relaunch XQuartz. This allows raw TCP connections to the X
server, not just the local Unix socket `ssh -X` normally uses — a real
(if small, loopback-only-by-default) security tradeoff, so it's not applied
automatically by the script above; only turn it on if the standard path
above doesn't work.

**Desktop launcher (optional):** once XQuartz is set up, `./scripts/build_mac_launchers.sh`
builds two double-clickable `.app` icons on the Desktop — the Mac
equivalent of `VacDepoctrl.desktop` on the Pi:

- **VacDep Remote.app** — picks a rig from a small known-rigs list baked
  into the app (edit `RIGS` in `scripts/build_mac_launchers.sh` and rebuild
  to add more — one entry auto-connects with no prompt, several show a
  choose-from-list dialog), then runs the `ssh -X` command above for you.
  Connects via the Pi's mDNS hostname (`av.local`) rather than a raw IP —
  DHCP has moved this rig's address before, but the mDNS name survives
  that. The SSH password itself is left to `ssh`'s own normal interactive
  Terminal prompt (secure, no extra tooling) rather than something like
  `sshpass`.
- **VacDep Simulation.app** — runs Simulation Mode locally (see below);
  no Pi or XQuartz-to-Pi connection needed, just XQuartz itself.

Both open Terminal.app rather than running silently, since `main.py`'s
startup self-test prints failures to the console before any GUI window
exists — same reasoning as `Terminal=true` in the Pi's `.desktop` file.
First launch of either needs a one-time right-click → Open to bypass
Gatekeeper's unsigned-app warning.

> [!note] Live network discovery was tried and doesn't work here
> mDNS *service* browsing (`dns-sd -B _ssh._tcp`) was the first approach
> tried for "find the Pi automatically" — it doesn't find this rig, since
> Avahi on the Pi isn't advertising `_ssh._tcp` (only plain hostname
> resolution works, which is what `av.local` above relies on). A maintained
> list is simply more reliable than scanning here.

### Windows

Two options — pick one:

- **MobaXterm** (recommended — simplest, one tool): install it, open a new
  SSH session to the Pi. X11 forwarding is enabled by default; its bundled
  X server starts automatically.
- **VcXsrv + PuTTY**: install VcXsrv, run **XLaunch** with *"Disable access
  control"* checked and leave it running, then in PuTTY set
  **Connection → SSH → X11 → Enable X11 forwarding** (X display location
  `localhost:0`) before connecting.

Either way, once connected: `source_vacdep && cd ~/VacDepoctrl && python main.py`.

### Linux

Usually nothing to install. A native X11 desktop session supports `ssh -X`
out of the box; a Wayland desktop on Linux ships `Xwayland` by default too
(unlike macOS/Windows, which have no X server at all). Just:

```bash
ssh -X av@<pi-ip>
source_vacdep && cd ~/VacDepoctrl && python main.py
```

---

## Web Dashboard

Any browser on the LAN gets the full live interface — readouts, graphs, and
controls — at:

```
http://av.local:8080          (or http://<pi-ip>:8080)
```

No app, no XQuartz, no SSH, no per-OS setup; works from a phone. Served by
`ui/web_ui.py` (stdlib HTTP + Server-Sent Events — nothing to install) with the
page in `ui/web/index.html` (self-contained, no CDN: renders on a LAN with no
internet).

**Parallel by design, never a replacement.** The web dashboard is a second
*view* of the same running `main.py` — the local Tkinter GUI always runs
regardless (`WEB_UI_ENABLED` only controls the browser side). A network
problem can therefore only ever cost the browser page; the control loop and
the local GUI on the rig don't know or care whether anyone is connected. The
page makes staleness unmissable: if the stream stops for >3 s it greys out
behind a DISCONNECTED banner rather than silently showing frozen numbers.

**Commands are the same code path as the local buttons.** Every browser
action dispatches the exact `_try_*()` function the corresponding Tkinter
button calls — same argon-pressure guards, same state-machine locks, same
confirmation gates (Confirm Plasma, Confirm Pump Off, Clear Fault). Every
web command is appended to `sputter_ctrl.log` with the client's IP, so the
audit trail records who did what from where.

> [!warning] No authentication
> Anyone on the LAN who can reach port 8080 can operate the rig — the same
> trust model as the Pi's own VNC/SSH access. Don't expose the Pi to a
> network you don't control; set `WEB_UI_ENABLED = False` in `config.py` to
> not open the port at all.

Troubleshooting: browsers with **HTTPS-Only mode** (Firefox especially)
rewrite a bare `<ip>:8080` to `https://` and fail with
`SSL_ERROR_RX_RECORD_TOO_LONG` — the server is plain HTTP, so the URL must
start with an explicit `http://`. The Tkinter header shows the full URL in a
selectable field with a Copy button for exactly this reason.

> [!warning] Deploy this feature as a set, not piecemeal
> `WEB_UI_ENABLED` lives in `config.py`, but the code it depends on
> (`ui/web_ui.py`, `ui/web/index.html`) are separate files. A partial `scp` that
> ships a `config.py` with `WEB_UI_ENABLED = True` but not the other two
> crashes `main.py` on startup with `ModuleNotFoundError: No module named
> 'web_ui'` — **every** launch path fails identically (desktop icon, SSH -X,
> plain SSH), since the crash happens at import time before Tkinter ever
> gets a chance to open a window. Hit and fixed 2026-07-12. Always deploy
> `config.py` together with the whole `ui/` folder, or set
> `WEB_UI_ENABLED = False` on the Pi if you're deliberately deploying
> without the dashboard for now.

---

## Simulation Mode

Runs the full GUI and control loop — state machine, PID loop, cross-sensor
checks, plasma detection — on any machine with no Pi, no sensors, and no
GPIO/I2C/serial hardware attached. Useful for developing/demoing this
project, or just poking at the UI without risking anything.

```bash
SPUTTER_SIM=1 python main.py
# or
python main.py --sim
```

`sim/sim_hardware.py` installs fake `RPi.GPIO` / `adafruit_ads1x15` /
`adafruit_extended_bus` / `serial` modules into `sys.modules` before
`main.py`'s own hardware imports run (the same technique the hardware-free
test suite uses) — but unlike the test suite's static, manually-set values,
these are backed by a live physics model (`ChamberSim`) that reacts to
whatever the real control loop actually commands: turbo RPM ramps when the
enable opto goes high, pressure falls while pumping and rises when the
turbo valve opens or the MFC commands flow, MFC measured flow chases
commanded flow with a lag, etc. The window shows an unmissable orange
"SIMULATION MODE" banner so it's never confused with a real run.

**Plasma strikes are manual, not automatic.** An early version auto-triggered
the simulated variac current from a flow+low-pressure heuristic, but that
fired during ARGON_FLUSH itself — before any real ignition attempt, since
the PID legitimately drives flow/pressure into the same range just
converging on the flush target. `_ignite_plasma()` is still a stub on real
hardware too, so nothing should auto-decide this in the simulation either.
Instead, Simulation Mode adds a **"Plasma Strike (SIM)"** toggle button to
the Controls panel — click it whenever you want to simulate the plasma
actually igniting; it stays exactly as set until toggled again.

On macOS, `./scripts/build_mac_launchers.sh` builds a double-clickable
**VacDep Simulation.app** — see [Remote GUI Access](#remote-gui-access) above.

---

## Configuration

All tunable parameters are in `config.py`. Key constants:

```python
# I2C
I2C_BUS_NUMBER               = 1       # hardware I2C1 on GPIO2/3
ADS1115_I2C_ADDRESS          = 0x48
ARGON_DAC_I2C_ADDRESS        = 0x60

# GPIO (BCM)
GPIO_PIRANI_PIN              = 17      # turbo enable opto
GPIO_MFC_VALVE_CLOSE_PIN     = 27      # emergency valve close
GPIO_TURBO_VALVE_PIN         = 22      # turbo inlet valve relay (was GPIO 4 — dead pad)

# Pressure thresholds (post-divider volts unless noted)
IDLE_PRESSURE_MAX_VOLTAGE    = 2.71    # 10 mbar  — pump-down gate
PUMP_DOWN_COMPLETE_VOLTAGE   = 0.3     # PUMP_DOWN → READY gate
ARGON_FLUSH_TARGET_VOLTAGE   = 1.287   # 0.09 mbar — plasma ignition pressure
VENTING_COMPLETE_VOLTAGE     = 3.0     # VENTING → IDLE threshold (near-atmosphere; see Pressure Reference)
SPUTTER_TARGET_MAX_MBAR      = 0.05    # cap on the operator-settable Sputter P field
ARGON_PRESSURE_MIN_PSI       = 15.0    # floor on the operator-settable Argon PSI field

# Turbo pump RPM (tach on ADC A2) and inlet valve interlock
ADC_CHANNEL_TURBO_RPM        = 2
TURBO_RPM_VOLTAGE_FULL_SCALE = 3.3     # volts at A2 for full-scale RPM
TURBO_RPM_FULL_SCALE         = 90000.0 # RPM at full-scale voltage
TURBO_VALVE_OPEN_RPM_MAX     = 35000   # inlet valve opens once RPM drops to/below this
TURBO_VALVE_CONFIRM_SAMPLES  = 3       # consecutive reads required before opening (debounce)

# Pressure PID control
ARGON_FLUSH_FLOW_SETPOINT    = 150.0   # sccm — initial flow on flush entry
PRESSURE_CONTROL_KP          = 8.0     # sccm/V — proportional gain (tuned)
PRESSURE_CONTROL_KD          = 3.0     # sccm·s/V — derivative gain (tuned)
PRESSURE_CONTROL_KI          = 0.005   # sccm/(V·s) — integral gain
PRESSURE_CONTROL_ICLAMP      = 50.0    # sccm — anti-windup clamp (KI=0 is safe)

# Timing
PLASMA_IGNITION_TIMEOUT      = 120.0   # seconds — auto-abort if plasma not confirmed
POLLING_INTERVAL             = 0.2     # seconds between sensor reads
GUI_REFRESH_INTERVAL         = 200     # ms between GUI updates
ERROR_DISPLAY_SECONDS        = 10      # status-bar error auto-expiry

# MFC / DAC
MFC_FULL_SCALE               = 700.0   # sccm
MFC_GAS_CORRECTION_FACTOR    = 1.39    # Argon correction for MKS 1179A
ARGON_DAC_VREF               = 5.0
ARGON_DAC_RESOLUTION         = 4096

# Energy meter (PZEM-004T-100A, variac output — see Energy Meter section)
PZEM_SERIAL_PORT             = "/dev/ttyUSB0"
PZEM_SLAVE_ADDRESS           = 0xF8
PZEM_PLASMA_CURRENT_ON_A     = 1.0     # A — UNVALIDATED, bench-measure before trusting
PZEM_PLASMA_CURRENT_OFF_A    = 0.6     # A — hysteresis floor, must be < _ON_A
PZEM_PLASMA_CONFIRM_SAMPLES  = 3       # consecutive above-threshold reads to latch detection
```

### Tuning the Pressure PID Loop

Current tuned values (Kp=8, Kd=3) were arrived at empirically on hardware:

- Started at Kp=40 (original, P-only) — produced slow, large-amplitude oscillation
- Dropped to Kp=10 — oscillation reduced significantly but response was sluggish
- Raised to Kp=20, added Kd=3–7 — eliminated overshoot at the 0.09 mbar (ARGON_FLUSH) setpoint, but undershoot persisted at 0.007 mbar (SPUTTER_READY) since the same gains behave differently at very different flow regimes
- Settled at Kp=17→8 (further reduced after switching `POLLING_INTERVAL` from 0.5s to 0.2s, which made the derivative term ~2.5× more aggressive for the same physical Kd — **gains must be retuned whenever `POLLING_INTERVAL` changes**), Kd=7→3
- I-term added to address a small persistent offset; large Ki caused overshoot, kept small with anti-windup clamping (`PRESSURE_CONTROL_ICLAMP`). Setting Ki=0 while tuning is safe (no divide-by-zero).

If you change `POLLING_INTERVAL`, expect to retune Kd and Ki — both depend on `dt` between samples.

---

## GUI Guide

| Element | Description |
|---|---|
| **Pi IP** | Live IP address shown in header |
| **Process State** | Current state, colour-coded |
| **Safety Trip banner / Clear Fault** | Appears (red) in the Process State panel only when the global safety gate has forced a shutdown; see [Global Safety Gate](#global-safety-gate). Clearing does not fix the underlying condition — an unaddressed fault re-trips immediately |
| **Start Argon Flush** | Opens MFC valve, starts PID loop to 0.09 mbar |
| **Confirm Plasma** | Manually confirms plasma ignition; transitions to SPUTTER_READY. Highlights green once the PZEM confirms plasma-level current draw during PLASMA_IGNITING |
| **Auto-Confirm toggle** | Plasma panel. Off by default. When armed, a PZEM-confirmed detection auto-advances PLASMA_IGNITING → SPUTTER_READY without a click — see [Energy Meter](#energy-meter-pzem-004t-100a-plasma-ignition-sensing) |
| **PLASMA / PZEM readout / graph** | Plasma panel (replaces the old placeholder): live `plasma_detected` status, PZEM voltage/current/power/energy/frequency/power-factor, and one scrolling graph with a legend covering all but energy (shown as a numeric total instead) |
| **Start Sputter** | Begins sputtering from SPUTTER_READY |
| **Stop Sputter** | Ends sputtering, transitions directly to VENTING |
| **Vent** | Vents chamber to atmosphere |
| **Confirm Pump Off** | Hidden until atmospheric pressure is reached during VENTING; click completes the vent (closes the turbo inlet valve, transitions to IDLE) — see [Vent Completion Confirmation](#vent-completion-confirmation) |
| **E-STOP** | Immediate: kills flow, closes both valves (turbo valve by direct GPIO write — works even with a hung poll thread), drops opto, returns to IDLE and **latches**; Clear Fault to resume |
| **Voltage + Pressure (mbar)** | Live Pirani readings; mbar via log-linear calibration table |
| **OPTO** | Turbo Pump panel. Green = turbo enable opto on; Red = off |
| **T-VALVE** | Turbo Pump panel. Green `CLOSED` = inlet valve shut (normal); Orange `OPEN (venting)` = venting and turbo RPM has dropped to/below `TURBO_VALVE_OPEN_RPM_MAX` |
| **T-RPM / T-RPM V / turbo graph** | Own Turbo Pump panel (below Plasma, beside Pirani/MFC); turbo pump RPM (ADC A2), its raw ADC voltage, and a scrolling RPM graph, all read every tick |
| **Sputter P (mbar)** | Operator-set target pressure; press Set or Enter. Rejected (warning dialog) if ≤ 0 or > 0.05 mbar |
| **Argon PSI** | Operator-entered regulator pressure; ≥ 15 psi required for flush/sputter. Rejected (warning dialog) if < 15 psi |
| **Pirani graph** | Scrolling ADC voltage (lime, 0–4V, 60 samples) |
| **MFC graph** | Scrolling flow sccm (cyan) overlaid with DAC voltage (yellow dashed) |
| **DAC OUT** | Green = DAC found on I2C; Red = not detected |
| **Valve** | Green = released (MFC in control); Red = closed (emergency) |
| **Status bar** | Errors shown in red, auto-expire after 10 s |

---

## Known Limitations

- **Turbo enable opto (GPIO 17) is marginal**: the enable input draws ~15–30 mA, beyond a 4N35's ~10 mA saturated capability at legal GPIO LED drive. Currently only works with excess LED current. Proper fix (BC547 output buffer) designed but not yet installed.
- **Argon PSI guard is honor-system**: the ≥15 psi check reads an operator-entered value, not a sensor, and the entered value persists across runs. By design — this is a manual regulator reading, not something this rig senses directly.
- **No series protection resistors on ADC inputs yet** — recommended as general input protection.
- **`_ignite_plasma()` is a stub**: RF power supply trigger is not yet implemented.
- **PZEM plasma-detection thresholds are unvalidated placeholders** (`PZEM_PLASMA_CURRENT_ON_A`/`OFF_A`): guessed values, not yet measured against the real supply's no-load vs. struck-plasma current. This is why Auto-Confirm defaults off — see [Energy Meter](#energy-meter-pzem-004t-100a-plasma-ignition-sensing).
- **PZEM CT clamp not yet confirmed on the real variac-output load line**: a 2026-07-12 run with visually-confirmed plasma still read 0.00A and force-shut-down via `pzem_plasma_absent_check()`. Until the CT is verified clamped correctly on the live load conductor (and, if the real current is low relative to the CT's 100A rating, wound through with multiple turns — see [Energy Meter bring-up notes](#bring-up-notes--troubleshooting)), plasma auto-detection cannot be trusted; keep Auto-Confirm off and rely on the manual Confirm Plasma button.

---

## Roadmap

Goals only, near-term → eventual. Inspired in part by how production fabs structure
tool control: hardwired interlocks under software, standardized state/alarm/recipe
models (SECS/GEM), and fault detection built on ruthless data collection.

### Harden the platform

- [x] **Software armor**: global safety gate (`_force_safe_shutdown()`), software
      heartbeat/watchdog, startup self-test, persistent event log, config validation
      at launch — implemented in software; not yet validated on hardware. Still
      outstanding: a Pi-level hardware watchdog (`/dev/watchdog`, forced reboot if
      unpetted) — deliberately deferred, separate systemd/infra decision with its
      own tradeoffs (what state GPIOs land in across a forced reboot)
- [~] **Simulation mode**: fake-hardware flag so the full state machine + GUI run on
      any laptop — `sim/sim_hardware.py`, `SPUTTER_SIM=1 python main.py` or `--sim`.
      Extends the unit suite's static test fakes into a live interactive sim with a
      simple first-order physics model (`ChamberSim`) that reacts to real GPIO/DAC/
      serial writes from the actual control loop, not canned values
- [ ] **Trustworthy analog front-end**: protected, calibrated sensor inputs with the
      divider ratios measured rather than assumed (Pirani atmosphere anomaly resolved)

### Make it a deposition machine

- [ ] **First characterized film**: complete a full run and measure the result — the
      milestone everything above serves
- [~] **Full plasma integration**: automatic plasma detection via current sensing
      (PZEM-004T-100A on the variac output), cross-sensor checks, and a plasma GUI
      panel replacing the placeholder are implemented; auto-confirm is operator-
      armed and off by default until the current thresholds are bench-validated.
      Still open, deliberately deferred until after the shutter (below): supply
      trigger in `_ignite_plasma()` itself, with arc suppression confirmed in hardware
- [x] **True turbo protection**: RPM-based inlet valve interlock (ADC A2, tach
      output), replacing the pressure-based gate — implemented in software
      (`turbo_valve_step()`, `TURBO_VALVE_OPEN_RPM_MAX`); not yet validated
      against a real vent cycle on hardware
- [x] ~~**Full-range MFC control**: level-shifted 5V DAC path removing the ~46%
      flow ceiling~~ — cancelled 2026-07-10, not required
- [ ] **Per-state PID gain sets**: ARGON_FLUSH and SPUTTER_READY dynamics differ;
      gains should switch with state. Correct, not urgent — low priority
- [ ] **Shutter**: stepper-driven, blocks sputtering flux from the substrate during
      pre-sputter target cleaning. Blocked on hardware access and a few design
      decisions (vacuum-compatible actuation, driver hardware, position sensing,
      manual vs. state-machine-tied control) — not a software gap

### Operate like a fab tool

- [ ] **Data collection & FDC-lite**: log every run (pressure/flow/DAC traces),
      build known-good baselines, flag deviation — drift detection instead of
      surprise failures; dashboarding via Grafana/InfluxDB is the natural backend.
      Real requirement, sequenced after simulation mode lands
- [ ] **Process recipes**: runs defined as recipe files (target pressure, power,
      time, ramp profiles) executed start-to-finish — repeatability over
      button-pressing. Sequenced after data collection above
- [ ] **Alarm model**: separate operator-info messages from latched alarms that
      require acknowledgement, GEM-style
- [ ] **Maintenance counters**: target erosion time, pump hours, cycles since vent —
      scheduled maintenance instead of run-to-failure

### Eventual

- [ ] **Unattended operation**: headless mode, remote monitoring and alarm
      notifications — the point where the watchdog and plasma detection stop being
      optional
- [ ] **Host interface**: expose state/data/recipes over the network (simple JSON
      socket, or the `secsgem` Python library for a real SEMI E30 interface) so the
      tool can be driven like production fab equipment
- [ ] **Run-to-run control**: adjust the next recipe from measurements of the last
      film — closing the outermost loop
- [ ] **MCU delegation layer**: when commercial smart boxes (MFC, supply) get
      replaced by homebuilt hardware, delegate the fast loops to a dedicated
      microcontroller under the Pi (the SputterOS-shaped slot in this architecture)
- [ ] **Replicable kit**: documentation and BOM good enough that another lab can
      build this machine from the repo alone

### Pi 5 GPIO dependency note

Blinka 9.2.0 declares a dependency on legacy `RPi.GPIO`. Setup installs Blinka
first, then replaces that package with `rpi-lgpio` for Pi 5 support. Do not
install both together. `pip check` currently reports Blinka's missing `RPi.GPIO`
distribution even though `import RPi.GPIO` is supplied by `rpi-lgpio`. Re-run
setup after dependency upgrades that reinstall the legacy package.

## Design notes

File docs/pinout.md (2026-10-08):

# VacDepoctrl — Raspberry Pi 5 pin diagram

Physical header numbers are in the middle; GPIO names use BCM numbering.
View from above the header, with the pin-1 end at the top and odd pins on the
left. Locate pin 1 on the board before wiring; this is not the underside view.

```text
                         PIN-1 END
                          ┌───────┐
                  3.3 V   │ 1   2 │   5 V
 ADC + DAC SDA ← GPIO2    │ 3   4 │   5 V
 ADC + DAC SCL ← GPIO3    │ 5   6 │   GND → ADC + DAC ground
                 GPIO4    │ 7   8 │   GPIO14
                   GND    │ 9  10 │   GPIO15
  Turbo enable ← GPIO17   │11  12 │   GPIO18
     MFC close ← GPIO27   │13  14 │   GND
   Turbo valve ← GPIO22   │15  16 │   GPIO23 — former SDA; disconnect
                  3.3 V   │17  18 │   GPIO24 — former SCL; disconnect
                GPIO10    │19  20 │   GND
                 GPIO9    │21  22 │   GPIO25
                GPIO11    │23  24 │   GPIO8
                   GND    │25  26 │   GPIO7
           GPIO0 / ID_SD  │27  28 │   GPIO1 / ID_SC
                 GPIO5    │29  30 │   GND
                 GPIO6    │31  32 │   GPIO12
                GPIO13    │33  34 │   GND
                GPIO19    │35  36 │   GPIO16
                GPIO26    │37  38 │   GPIO20
                   GND    │39  40 │   GPIO21
                          └───────┘
```

Unmarked GPIOs have no assignment in the current controller configuration;
that does not establish whether a fitted HAT uses them. Pins 27/28 are the HAT
identification interface. Power pins are shown for orientation, not as an
instruction to change module power wiring.

## Shared I2C wiring

```mermaid
flowchart LR
    SDA["Pi pin 3 / GPIO2 · SDA1"] --- ASDA["ADS1115 SDA · 0x48"]
    SDA --- DSDA["MCP4725 SDA · 0x60"]
    SCL["Pi pin 5 / GPIO3 · SCL1"] --- ASCL["ADS1115 SCL"]
    SCL --- DSCL["MCP4725 SCL"]
    GND["Pi pin 6 · GND"] --- AGND["ADS1115 GND"]
    GND --- DGND["MCP4725 GND"]
```

Both devices share hardware bus **1**, configured for **100 kHz**. Power down
before moving the previous SDA/SCL wires from physical **16/18 → 3/5**.
Keep bus pull-ups at **3.3 V**, never 5 V. This diagram covers signal wiring;
retain the verified module supply and analog conditioning circuits.

## Control and analog connections

| Signal | Connection | Behavior / notes |
|---|---|---|
| Turbo enable | Pin 11 / GPIO17 → opto input circuit | HIGH enables; LOW disables |
| MFC emergency close | Pin 13 / GPIO27 → valve-close interface | LOW forces close; input mode releases override |
| Turbo inlet valve | Pin 15 / GPIO22 → BC547 relay driver | HIGH opens; LOW closes, per existing NC-contact wiring |
| Pirani pressure | Conditioned gauge output → ADS1115 A0 | Existing 0–10 V to 0–3.3 V divider |
| MFC flow feedback | Conditioned feedback → ADS1115 A1 | Existing input divider |
| Turbo RPM | Conditioned tach output → ADS1115 A2 | Configured 0–3.3 V range |
| MFC setpoint | MCP4725 OUT → existing buffer/gain stage → MFC | Configured 0–5 V output range after conditioning |
| PZEM meter | CP2102 USB serial adapter → Pi USB | Not a GPIO-header UART connection |

Control GPIOs connect to the existing interface circuits, not directly to coils
or high-voltage equipment. ESP32 autotransformer wiring is still being planned
and is not assigned here.

Source of controller assignments: [config.py](../config.py),
[Pirani driver](../drivers/pirani.py), and [MFC driver](../drivers/mfc_control.py).
Header reference: [Raspberry Pi GPIO documentation](https://www.raspberrypi.com/documentation/computers/raspberry-pi.html#gpio).

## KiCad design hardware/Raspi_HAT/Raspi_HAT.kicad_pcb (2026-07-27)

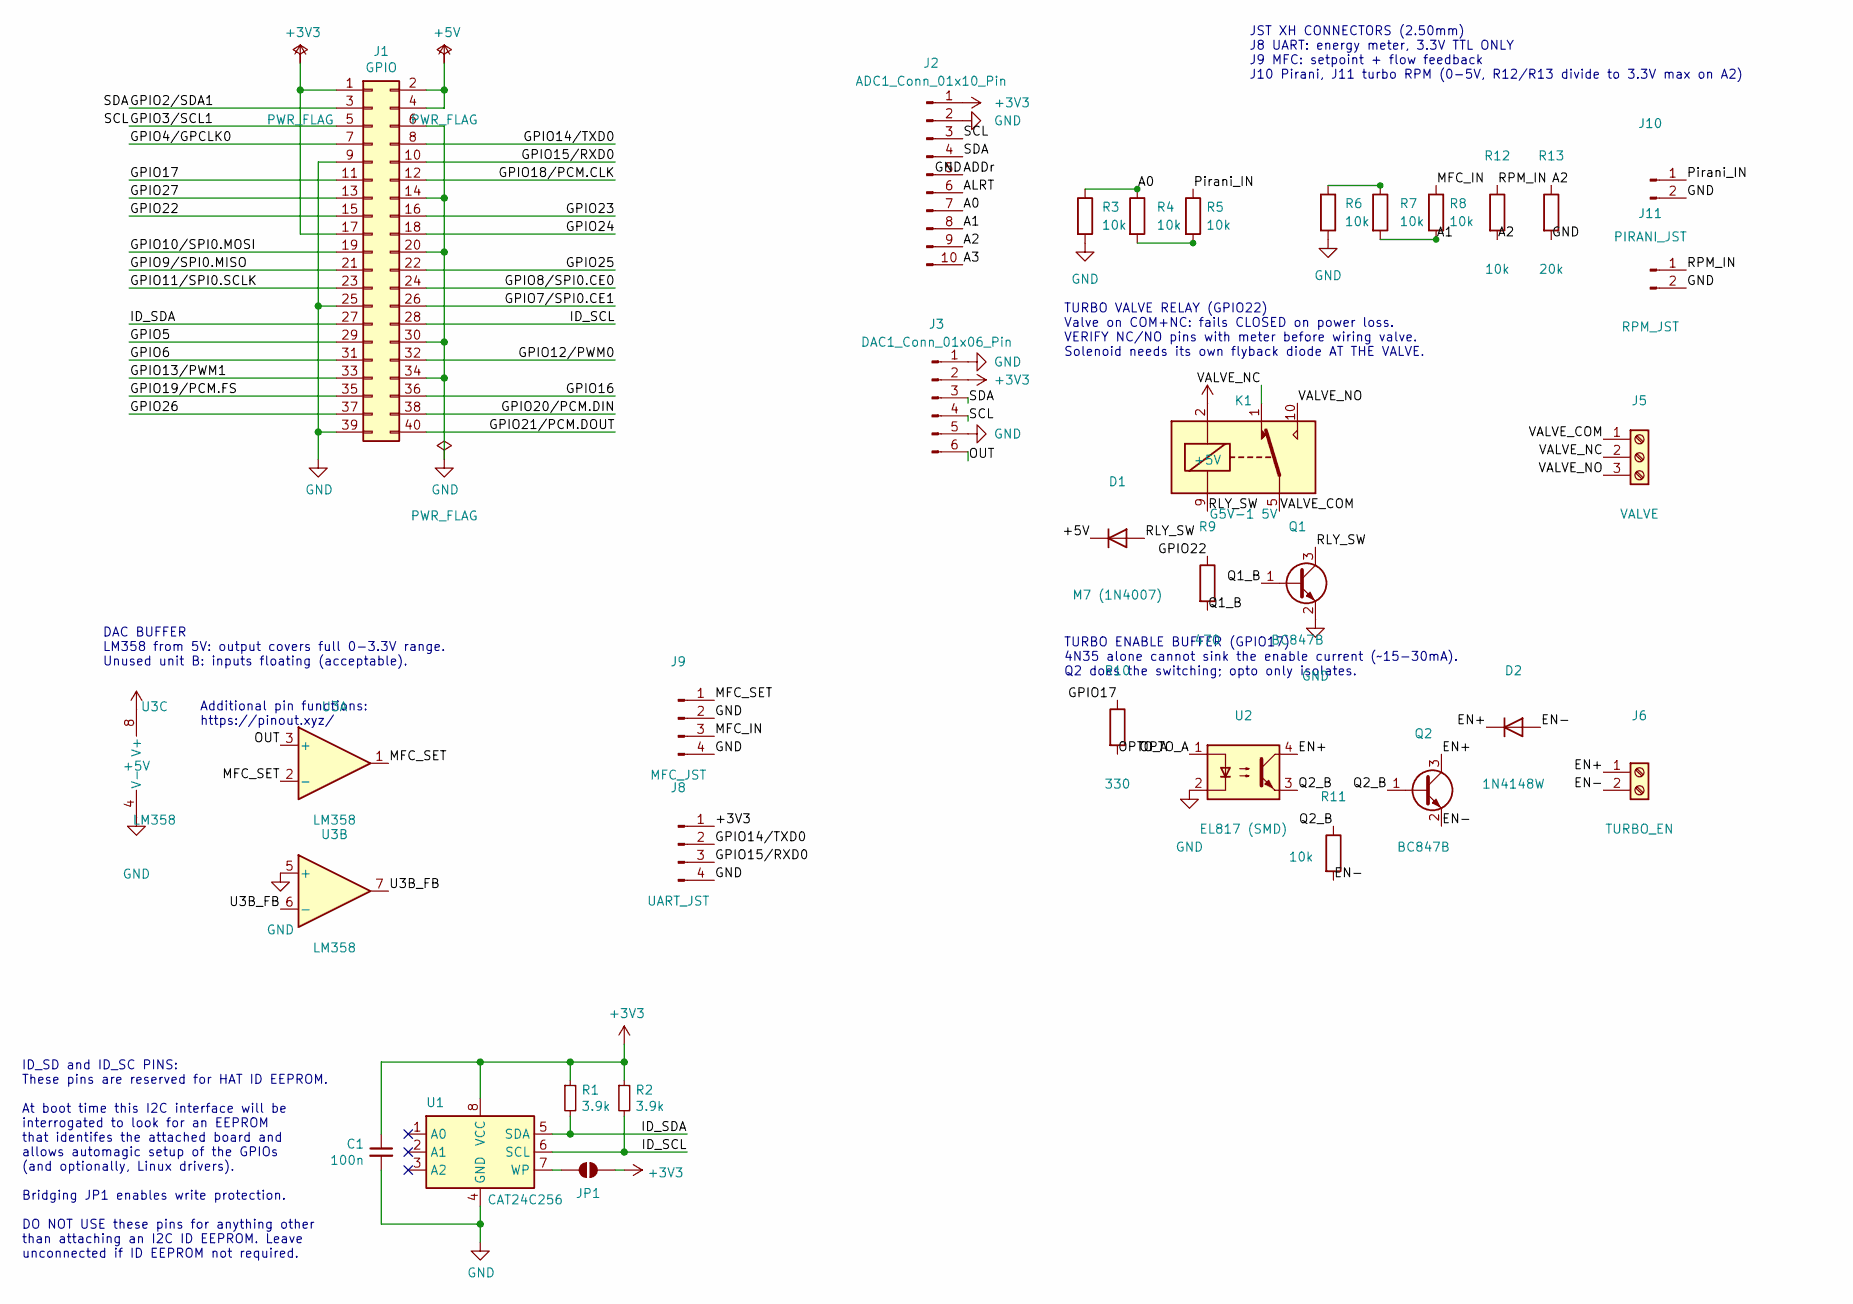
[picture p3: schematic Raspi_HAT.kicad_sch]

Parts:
C1: 100n; C_0805_2012Metric
D1: M7 (1N4007); D_SMA
D2: 1N4148W; D_SOD-123
J1: GPIO; PinSocket_2x20_P2.54mm_Vertical
J2: ADC1_Conn_01x10_Pin; PinSocket_1x10_P2.54mm_Vertical
J3: DAC1_Conn_01x06_Pin; PinSocket_1x06_P2.54mm_Vertical
J5: VALVE; TerminalBlock_Phoenix_MKDS-1,5-3-5.08_1x03_P5.08mm_Horizont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
J6: TURBO_EN; TerminalBlock_Phoenix_MKDS-1,5-2-5.08_1x02_P5.08mm_Horizont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
J8: UART_JST; JST_XH_B4B-XH-A_1x04_P2.50mm_Vertical
J9: MFC_JST; JST_XH_B4B-XH-A_1x04_P2.50mm_Vertical
J10: PIRANI_JST; JST_XH_B2B-XH-A_1x02_P2.50mm_Vertical
J11: RPM_JST; JST_XH_B2B-XH-A_1x02_P2.50mm_Vertical
JP1: ID_WP; SolderJumper-2_P1.3mm_Open_TrianglePad1.0x1.5mm
K1: G5V-1 5V; Relay_SPDT_Omron_G5V-1
Q1, Q2: BC847B; SOT-23
R1, R2: 3.9k; R_0805_2012Metric
R3, R4, R5, R6, R7, R8, R11, R12: 10k; R_0805_2012Metric
R9: 470; R_0805_2012Metric
R10: 330; R_0805_2012Metric
R13: 20k; R_0805_2012Metric
U1: CAT24C256; SOIC-8_3.9x4.9mm_P1.27mm
U2: EL817 (SMD); SO-4_7.6x3.6mm_P2.54mm
U3: LM358; SOIC-8_3.9x4.9mm_P1.27mm

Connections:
+3V3: C1.1, J1.1, J1.17, J2.1, J3.2, J8.1, JP1.2 (B), R1.1, R2.1, U1.8 (VCC)
+5V: D1.1 (K), J1.2, J1.4, K1.2, U3.8 (V+)
/A0: J2.7, R3.1, R4.1
/A1: J2.8, R7.2, R8.2
/A2: J2.9, R12.2, R13.1
/A3: J2.10
/ALRT: J2.6
/EN+: D2.1 (K), J6.1, Q2.3 (C), U2.4
/EN-: D2.2 (A), J6.2, Q2.2 (E), R11.2
/GPIO2/SDA1: J1.3, J2.4, J3.3
/GPIO3/SCL1: J1.5, J2.3, J3.4
/GPIO4/GPCLK0: J1.7
/GPIO5: J1.29
/GPIO6: J1.31
/GPIO7/SPI0.CE1: J1.26
/GPIO8/SPI0.CE0: J1.24
/GPIO9/SPI0.MISO: J1.21
/GPIO10/SPI0.MOSI: J1.19
/GPIO11/SPI0.SCLK: J1.23
/GPIO12/PWM0: J1.32
/GPIO13/PWM1: J1.33
/GPIO14/TXD0: J1.8, J8.2
/GPIO15/RXD0: J1.10, J8.3
/GPIO16: J1.36
/GPIO17: J1.11, R10.1
/GPIO18/PCM.CLK: J1.12
/GPIO19/PCM.FS: J1.35
/GPIO20/PCM.DIN: J1.38
/GPIO21/PCM.DOUT: J1.40
/GPIO22: J1.15, R9.1
/GPIO23: J1.16
/GPIO24: J1.18
/GPIO25: J1.22
/GPIO26: J1.37
/GPIO27: J1.13
/ID_SCL: J1.28, R2.2, U1.6 (SCL)
/ID_SDA: J1.27, R1.2, U1.5 (SDA)
/MFC_IN: J9.3, R8.1
/MFC_SET: J9.1, U3.1, U3.2 (-)
/OPTO_A: R10.2, U2.1
/OUT: J3.6, U3.3 (+)
/Pirani_IN: J10.1, R5.1
/Q1_B: Q1.1 (B), R9.2
/Q2_B: Q2.1 (B), R11.1, U2.3
/RLY_SW: D1.2 (A), K1.9, Q1.3 (C)
/RPM_IN: J11.1, R12.1
/U3B_FB: U3.6 (-), U3.7
/VALVE_COM: J5.1, K1.5, K1.6
/VALVE_NC: J5.2, K1.1
/VALVE_NO: J5.3, K1.10
GND: C1.2, J1.6, J1.9, J1.14, J1.20, J1.25, J1.30, J1.34, J1.39, J2.2, J2.5, J3.1, J3.5, J8.4, J9.2, J9.4, J10.2, J11.2, Q1.2 (E), R3.2, R6.2, R13.2, U1.4 (GND), U2.2, U3.4 (V-), U3.5 (+)
unnamed: JP1.1 (A), U1.7 (WP)
unnamed: R4.2, R5.2
unnamed: R6.1, R7.1

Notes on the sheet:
Additional pin functions: https://pinout.xyz/
TURBO ENABLE BUFFER (GPIO17) 4N35 alone cannot sink the enable current (~15-30mA). Q2 does the switching; opto only isolates.
ID_SD and ID_SC PINS: These pins are reserved for HAT ID EEPROM. At boot time this I2C interface will be interrogated to look for an EEPROM that identifes the attached board and allows automagic setup of the GPIOs (and optionally, Linux drivers). Bridging JP1 enables write protection. DO NOT USE th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
JST XH CONNECTORS (2.50mm) J8 UART: energy meter, 3.3V TTL ONLY J9 MFC: setpoint + flow feedback J10 Pirani, J11 turbo RPM (0-5V, R12/R13 divide to 3.3V max on A2)
TURBO VALVE RELAY (GPIO22) Valve on COM+NC: fails CLOSED on power loss. VERIFY NC/NO pins with meter before wiring valve. Solenoid needs its own flyback diode AT THE VALVE.
DAC BUFFER LM358 from 5V: output covers full 0-3.3V range. Unused unit B: inputs floating (acceptable).

Board: 2 copper layers, 36 parts (1 on the bottom side), 32 nets, no tracks yet.

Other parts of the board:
MH1, MH2, MH3, MH4: MountingHole_2.7mm_M2.5

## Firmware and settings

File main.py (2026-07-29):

#!/usr/bin/env python3
"""
main.py — Sputter Vacuum Controller
State machine + live scrolling graphs for Pirani voltage and MFC flow.
"""

import os
import sys

# Simulation mode: SPUTTER_SIM=1 python main.py, or python main.py --sim.
# Installs fake hardware modules into sys.modules BEFORE the real ones are
# imported below -- see sim/sim_hardware.py. Everything else in this file runs
# completely unmodified against them; nothing downstream needs to know.
SIM_MODE = os.environ.get("SPUTTER_SIM") == "1" or "--sim" in sys.argv
_sim_chamber = None
if SIM_MODE:
    from sim import sim_hardware
    _sim_chamber = sim_hardware.install()

# Single-instance lock, taken BEFORE any hardware is touched: two instances
# fighting over the same DAC/valve-relay/opto pins is a real hazard, not a
# theoretical one (it has happened -- the "channel already in use" GPIO
# warnings during remote-GUI experiments were exactly this). flock() is
# released by the kernel on ANY process exit, including SIGKILL, so a crash
# can never leave a stale lock behind. The handle must stay referenced for
# the life of the process. (*.lock is gitignored.)
import fcntl
_instance_lock = open(os.path.join(os.path.dirname(os.path.abspath(__file__)),
                                   ".sputter_ctrl.lock"), "w")
try:
    fcntl.flock(_instance_lock, fcntl.LOCK_EX | fcntl.LOCK_NB)
except OSError:
    print("Another instance of main.py is already running (holding "
          ".sputter_ctrl.lock) — refusing to start a second control loop "
          "on the same hardware.", file=sys.stderr)
    sys.exit(1)

import logging
import math
import socket
import threading
import time
import tkinter as tk
from tkinter import messagebox

import RPi.GPIO as GPIO
import adafruit_ads1x15.ads1115 as ADS
from adafruit_extended_bus import ExtendedI2C

from config import (
    ADC_GAIN,
    POLLING_INTERVAL,
    GUI_REFRESH_INTERVAL,
    ERROR_DISPLAY_SECONDS,
    GRAPH_MAX_SAMPLES,
    GRAPH_PIRANI_MIN,
    GRAPH_PIRANI_MAX,
    GRAPH_PIRANI_COLOR,
    GRAPH_MFC_MIN,
    GRAPH_MFC_MAX,
    GRAPH_MFC_COLOR,
    GRAPH_TURBO_RPM_MIN,
    GRAPH_TURBO_RPM_MAX,
    GRAPH_TURBO_RPM_COLOR,
    IDLE_PRESSURE_MAX_VOLTAGE,
    PUMP_DOWN_COMPLETE_VOLTAGE,
    VENTING_COMPLETE_VOLTAGE,
    ARGON_FLUSH_TARGET_VOLTAGE,
    ARGON_FLUSH_FLOW_SETPOINT,
    SPUTTER_READY_TARGET_VOLTAGE,
    SPUTTER_TARGET_MAX_MBAR,
    ARGON_PRESSURE_MIN_PSI,
    PLASMA_IGNITION_TIMEOUT,
    PRESSURE_CONTROL_KP,
    ADS1115_I2C_ADDRESS,
    ARGON_DAC_I2C_ADDRESS,
    ARGON_DAC_VREF,
    GPIO_PIRANI_PIN,
    GPIO_MFC_VALVE_CLOSE_PIN,
    GPIO_TURBO_VALVE_PIN,
    TURBO_VALVE_OPEN_RPM_MAX,
    TURBO_VALVE_CONFIRM_SAMPLES,
    VENTING_PUMP_OFF_PROMPT_RPM,
    TURBO_RPM_FULL_SCALE,
    TURBO_SPINUP_GRACE_SECONDS,
    TURBO_RPM_STALL_THRESHOLD,
    TURBO_RPM_DROP_GRACE_SECONDS,
    MFC_FULL_SCALE,
    MFC_FLOW_MIN_COMMANDED_SCCM,
    MFC_FLOW_RESPONSE_FRACTION,
    MFC_FLOW_GRACE_SECONDS,
    DAC_SATURATION_MARGIN_V,
    DAC_SATURATION_FLOW_FRACTION,
    DAC_SATURATION_GRACE_SECONDS,
    PRESSURE_CONVERGENCE_TOLERANCE_V,
    PRESSURE_CONVERGENCE_GRACE_SECONDS,
    STARTUP_GRACE_SECONDS,
    HEARTBEAT_TIMEOUT_SECONDS,
    CONSECUTIVE_EXCEPTION_LIMIT,
    SANE_VOLTAGE_MIN,
    SANE_VOLTAGE_MAX,
    SENSOR_RANGE_CONFIRM_SAMPLES,
    EVENT_LOG_FILENAME,
    I2C_BUS_NUMBER,
    PZEM_PLASMA_CURRENT_ON_A,
    PZEM_PLASMA_CURRENT_OFF_A,
    PZEM_PLASMA_CONFIRM_SAMPLES,
    PZEM_PLASMA_ABSENT_GRACE_SECONDS,
    PZEM_POWER_UNEXPECTED_GRACE_SECONDS,
    GRAPH_PZEM_VOLTAGE_MAX,
    GRAPH_PZEM_CURRENT_MAX,
    GRAPH_PZEM_POWER_MAX,
    GRAPH_PZEM_FREQ_MIN,
    GRAPH_PZEM_FREQ_MAX,
    WEB_UI_ENABLED,
    WEB_UI_PORT,
    WEB_UI_UPDATE_INTERVAL,
)
# Pirani calibration table: (mbar, gauge_voltage) from datasheet
# ADC voltage = gauge_voltage * 0.33 (resistor divider)
_PIRANI_CAL = [
    (999, 10.00), (850, 9.58), (800, 9.52), (700, 9.45), (600, 9.38),
    (500, 9.28),  (400, 9.20), (300, 9.15), (200, 9.08), (100, 9.04),
    (50,  8.85),  (25,  8.70), (20,  8.60), (15,  8.40), (10,  8.20),
    (9,   8.10),  (8,   8.00), (7,   7.85), (6,   7.75), (5,   7.55),
    (4,   7.28),  (3,   6.92), (2,   6.27), (1,   5.70), (0.9, 5.60),
    (0.8, 5.51),  (0.7, 5.45), (0.6, 5.31), (0.5, 5.15), (0.4, 4.90),
    (0.3, 4.52),  (0.2, 4.28), (0.1, 3.98), (0.09, 3.90),(0.08, 3.75),
    (0.07, 3.64), (0.06, 3.55),(0.05, 3.44),(0.04, 3.23),(0.03, 2.93),
    (0.02, 2.50), (0.01, 1.55),(0.009, 1.45),(0.008, 1.30),(0.007, 1.10),
    (0.006, 0.95),(0.005, 0.80),(0.004, 0.65),(0.003, 0.50),(0.002, 0.35),
    (0.001, 0.12),(0.0, 0.01),
]
# Pre-scale by divider ratio so table is in ADC volts
_PIRANI_CAL_ADC = [(p, v * 0.33) for p, v in _PIRANI_CAL]

def mbar_to_adc_voltage(mbar):
    """Interpolate Pirani calibration table using log-linear interpolation.
    Interpolates linearly in log-pressure space to match the gauge physical response.
    """
    cal = _PIRANI_CAL_ADC
    if mbar >= cal[0][0]:  return cal[0][1]
    if mbar <= cal[-1][0]: return cal[-1][1]
    for i in range(len(cal) - 1):
        p_hi, v_hi = cal[i]
        p_lo, v_lo = cal[i+1]
        if p_lo <= mbar <= p_hi:
            if p_lo <= 0: p_lo = 1e-6
            t = (math.log(mbar) - math.log(p_lo)) / (math.log(p_hi) - math.log(p_lo))
            return v_lo + t * (v_hi - v_lo)
    return cal[-1][1]

def adc_voltage_to_mbar(voltage):
    """Inverse of mbar_to_adc_voltage: ADC voltage -> pressure in mbar.
    Interpolates linearly in voltage, logarithmically in pressure, matching
    the Pirani gauge's log response (same DHPG-015 calibration table).
    """
    cal = _PIRANI_CAL_ADC
    if voltage >= cal[0][1]:  return cal[0][0]   # >= 3.30 V: atmosphere (999)
    if voltage <= cal[-1][1]: return cal[-1][0]  # <= 0.0033 V: over-range (0)
    for i in range(len(cal) - 1):
        p_hi, v_hi = cal[i]
        p_lo, v_lo = cal[i+1]
        if v_lo <= voltage <= v_hi:
            if p_lo <= 0: p_lo = 1e-6
            t = (voltage - v_lo) / (v_hi - v_lo)
            return math.exp(math.log(p_lo) + t * (math.log(p_hi) - math.log(p_lo)))
    return cal[-1][0]

def turbo_valve_step(venting, rpm, valve_open, below_ticks):
    """Debounced turbo inlet valve latch. Pure decision logic — no I/O.

    Driven by turbo pump RPM (tach on ADC A2), not chamber pressure: the
    rotor's own speed is the direct signal for whether it's safe to admit
    gas, rather than inferring rotor state from pressure. The valve may
    only open during VENTING, and only after TURBO_VALVE_CONFIRM_SAMPLES
    consecutive readings at or below TURBO_VALVE_OPEN_RPM_MAX: a single
    corrupted read on the software I2C bus (EMI bit-flips return garbage
    without raising) must not latch the valve open. An above-threshold
    reading resets the count. Once open, the valve stays latched open (no
    relay chatter) until VENTING is left; leaving VENTING also clears the
    count so a partial count can't carry into the next vent. Returns
    (valve_open, below_ticks).
    """
    if not venting:
        return False, 0
    if valve_open:
        return True, 0
    if rpm <= TURBO_VALVE_OPEN_RPM_MAX:
        below_ticks += 1
        return below_ticks >= TURBO_VALVE_CONFIRM_SAMPLES, below_ticks
    return False, 0

def turbo_spinup_check(opto_enabled, rpm, on_since, now):
    """Cross-sensor check: opto_enabled (GPIO 17) is us commanding the turbo
    to spin up; rpm (ADC A2) is the pump reporting back. Individually both
    can look "valid" while still disagreeing -- flags if opto has been on
    for TURBO_SPINUP_GRACE_SECONDS but the rotor still reads below
    TURBO_RPM_STALL_THRESHOLD (turbo fault, RPM sensor fault, or wiring
    fault). `on_since` is the timestamp opto first turned on, threaded back
    in by the caller each tick so this function stays pure. Returns
    (flagged, on_since).
    """
    if not opto_enabled:
        return False, None
    if on_since is None:
        on_since = now
    flagged = (rpm < TURBO_RPM_STALL_THRESHOLD
               and (now - on_since) >= TURBO_SPINUP_GRACE_SECONDS)
    return flagged, on_since

def turbo_rpm_drop_check(opto_enabled, rpm, confirmed_healthy, dropped_since, now):
    """Cross-sensor check: distinct fault from turbo_spinup_check, which
    only catches "never spun up". Once RPM has confirmed healthy spin
    (exceeded TURBO_RPM_STALL_THRESHOLD at least once since opto turned
    on), a sustained drop back below that threshold while opto is still
    enabled means the turbo was running and is now failing/degrading, not
    just slow to start. `confirmed_healthy` and `dropped_since` are
    threaded back in by the caller each tick so this stays pure. Returns
    (flagged, confirmed_healthy, dropped_since).
    """
    if not opto_enabled:
        return False, False, None
    if rpm >= TURBO_RPM_STALL_THRESHOLD:
        return False, True, None
    if not confirmed_healthy:
        return False, False, None
    if dropped_since is None:
        dropped_since = now
    flagged = (now - dropped_since) >= TURBO_RPM_DROP_GRACE_SECONDS
    return flagged, confirmed_healthy, dropped_since

def mfc_flow_check(flow_target, measured_flow, stalled_since, now):
    """Cross-sensor check: flow_target (what we commanded the MFC via the
    DAC) vs measured_flow (the MFC's own analog feedback on A1). Flags if a
    meaningful commanded flow has stayed well above measured flow for
    MFC_FLOW_GRACE_SECONDS -- the actuator isn't responding (dead MFC,
    disconnected wiring, empty gas supply), rather than the PID loop just
    still settling. Returns (flagged, stalled_since).
    """
    commanding = flow_target >= MFC_FLOW_MIN_COMMANDED_SCCM
    responding = measured_flow >= flow_target * MFC_FLOW_RESPONSE_FRACTION
    if not commanding or responding:
        return False, None
    if stalled_since is None:
        stalled_since = now
    flagged = (now - stalled_since) >= MFC_FLOW_GRACE_SECONDS
    return flagged, stalled_since

def dac_saturation_flow_check(dac_voltage, measured_flow, stalled_since, now):
    """Cross-sensor check: is the DAC pegged at (or very near) its output
    ceiling while measured flow stays far below what full-scale should
    deliver? DAC saturation means the PID has given up on proportional
    correction and is commanding maximum output -- a stronger fault signal
    than mfc_flow_check's target/measured mismatch: valve stuck, line
    blocked, or gas supply empty. Returns (flagged, stalled_since).
    """
    saturated = dac_voltage >= (ARGON_DAC_VREF - DAC_SATURATION_MARGIN_V)
    responding = measured_flow >= MFC_FULL_SCALE * DAC_SATURATION_FLOW_FRACTION
    if not saturated or responding:
        return False, None
    if stalled_since is None:
        stalled_since = now
    flagged = (now - stalled_since) >= DAC_SATURATION_GRACE_SECONDS
    return flagged, stalled_since

def pressure_convergence_check(current_voltage, target_voltage, diverging_since, now):
    """Cross-sensor check: is the pressure PID loop actually converging on
    its own target? Flags if |current - target| has stayed above
    PRESSURE_CONVERGENCE_TOLERANCE_V for PRESSURE_CONVERGENCE_GRACE_SECONDS
    despite the control loop running every tick -- suggests a leak, stuck
    valve, or MFC fault rather than normal settling time. Returns
    (flagged, diverging_since).
    """
    error = abs(current_voltage - target_voltage)
    if error <= PRESSURE_CONVERGENCE_TOLERANCE_V:
        return False, None
    if diverging_since is None:
        diverging_since = now
    flagged = (now - diverging_since) >= PRESSURE_CONVERGENCE_GRACE_SECONDS
    return flagged, diverging_since

def vent_complete_ready(pending, confirmed):
    """Pure decision: has VENTING earned its transition to IDLE? Requires
    BOTH a latched atmospheric-pressure indication AND explicit operator
    confirmation that the primary/roughing pump has been turned off.

    `pending` must already be latched by the caller (see _poll()'s VENTING
    branch: it sets `_state["vent_complete_pending"]` True on first
    crossing VENTING_COMPLETE_VOLTAGE and never clears it back to False on
    its own) rather than re-checking raw pressure here -- a first version
    checked the instantaneous voltage fresh every tick, which meant a
    single noisy/borderline reading hovering right at the threshold made
    the "Confirm Pump Off" button flicker in and out of existence every
    poll tick. Every other threshold in this file is debounced or latched
    for exactly this reason; this one is no different.

    Pressure alone used to auto-complete this via sm.update(), but that let
    the turbo inlet valve reclose (turbo_valve_step() closes it the instant
    `venting` goes False) the moment atmosphere was reached — before the
    operator had any real chance to react to the "turn off the primary
    pump" cue, let alone actually flip the switch. Now owned exclusively by
    _poll(), the same way ARGON_FLUSH -> PLASMA_IGNITING is (see
    state_machine.py's update() docstring).
    """
    return pending and confirmed


_PZEM_PLASMA_EXPECTED_STATES = ("PLASMA_IGNITING", "SPUTTER_READY", "SPUTTERING")


def plasma_detect_step(current_a, detected, confirm_ticks):
    """Debounced hysteresis latch for plasma-ignition detection via
    variac-side AC current draw (PZEM-004T-100A on the sputtering supply's
    variac output). Mirrors the turbo enable opto's ON/OFF hysteresis
    pattern: a rising edge must clear PZEM_PLASMA_CURRENT_ON_A for
    PZEM_PLASMA_CONFIRM_SAMPLES consecutive ticks before `detected` latches
    True -- a single Modbus CRC glitch must not flip a status other
    cross-sensor checks (and the operator-armed auto-confirm toggle) key
    off of. A falling edge below PZEM_PLASMA_CURRENT_OFF_A clears
    immediately -- no debounce needed to fail safe toward "not detected".
    Between the two thresholds, holds the previous state and resets the
    confirm count (same dead-band behavior as the opto hysteresis).
    Returns (detected, confirm_ticks).
    """
    if current_a >= PZEM_PLASMA_CURRENT_ON_A:
        if detected:
            return True, 0
        confirm_ticks += 1
        return confirm_ticks >= PZEM_PLASMA_CONFIRM_SAMPLES, confirm_ticks
    if current_a <= PZEM_PLASMA_CURRENT_OFF_A:
        return False, 0
    return detected, 0


def pzem_plasma_absent_check(state, plasma_detected, absent_since, now):
    """Cross-sensor check: SPUTTER_READY/SPUTTERING both assume plasma is
    already lit (PLASMA_IGNITING's own PLASMA_IGNITION_TIMEOUT owns the
    "never struck" case and is deliberately excluded here -- flagging a
    still-igniting discharge as "absent" would just duplicate that abort
    path with a shorter, unrelated grace period). If PZEM stops seeing
    plasma-level current once actually in one of those two states, that's
    an arc dropout or the plasma extinguishing mid-run. Flags after
    PZEM_PLASMA_ABSENT_GRACE_SECONDS. Returns (flagged, absent_since).
    """
    if state not in ("SPUTTER_READY", "SPUTTERING"):
        return False, None
    if plasma_detected:
        return False, None
    if absent_since is None:
        absent_since = now
    flagged = (now - absent_since) >= PZEM_PLASMA_ABSENT_GRACE_SECONDS
    return flagged, absent_since


def pzem_power_unexpected_check(state, plasma_detected, unexpected_since, now):
    """Cross-sensor check: plasma-level current draw on the variac while the
    process isn't attempting ignition at all (IDLE/PUMP_DOWN/READY/
    ARGON_FLUSH/VENTING) means the HV/RF supply is energized when it
    shouldn't be -- a stuck relay, a supply left live, or a wiring fault --
    not a legitimate reading at any of those states. Flags after
    PZEM_POWER_UNEXPECTED_GRACE_SECONDS. Returns (flagged, unexpected_since).
    """
    if state in _PZEM_PLASMA_EXPECTED_STATES:
        return False, None
    if not plasma_detected:
        return False, None
    if unexpected_since is None:
        unexpected_since = now
    flagged = (now - unexpected_since) >= PZEM_POWER_UNEXPECTED_GRACE_SECONDS
    return flagged, unexpected_since


def sensor_range_check(voltages, bad_ticks):
    """Global gate check: are all given ADC-derived voltages within a
    physically sane range (post-divider signals referenced to the Pi's
    3.3V rail)? A reading outside SANE_VOLTAGE_MIN/MAX means a
    disconnected, shorted, or miswired sensor -- not a legitimate reading
    at any pressure/flow/speed. Debounced like every other hardware-facing
    check here: a single corrupted I2C sample (EMI bit-flip, no raised
    exception) must not immediately trip a full shutdown; requires
    SENSOR_RANGE_CONFIRM_SAMPLES consecutive bad ticks. Returns
    (flagged, bad_ticks).
    """
    bad = any(v < SANE_VOLTAGE_MIN or v > SANE_VOLTAGE_MAX for v in voltages)
    if not bad:
        return False, 0
    bad_ticks += 1
    return bad_ticks >= SENSOR_RANGE_CONFIRM_SAMPLES, bad_ticks

def config_sanity_failures():
    """Pure config-invariant checks, no I/O. Returns a list of failure
    strings (empty if all pass). Mirrors TestConfigSanity in the test
    suite but also runs live at startup, so a bad future edit to config.py
    is caught before the app runs with a broken safety threshold -- this is
    exactly the class of bug that once shipped here: VENTING_COMPLETE_VOLTAGE
    was 2.5V (~5 mbar, nowhere near atmosphere) instead of near-atmosphere.
    """
    failures = []
    if not (PUMP_DOWN_COMPLETE_VOLTAGE < ARGON_FLUSH_TARGET_VOLTAGE
            < IDLE_PRESSURE_MAX_VOLTAGE < VENTING_COMPLETE_VOLTAGE):
        failures.append(
            "Pressure thresholds out of order: expected "
            "PUMP_DOWN_COMPLETE_VOLTAGE < ARGON_FLUSH_TARGET_VOLTAGE < "
            "IDLE_PRESSURE_MAX_VOLTAGE < VENTING_COMPLETE_VOLTAGE."
        )
    if not (0 < TURBO_VALVE_OPEN_RPM_MAX < TURBO_RPM_FULL_SCALE):
        failures.append("TURBO_VALVE_OPEN_RPM_MAX out of range (0, TURBO_RPM_FULL_SCALE).")
    pins = [GPIO_PIRANI_PIN, GPIO_MFC_VALVE_CLOSE_PIN, GPIO_TURBO_VALVE_PIN]
    if len(pins) != len(set(pins)):
        failures.append("GPIO pin collision in config.py.")
    if any(pin in (2, 3, 4, 23, 24) for pin in pins):
        failures.append("A configured GPIO pin is on the dead/reserved list (2, 3, 4, 23, 24).")
    if not (PZEM_PLASMA_CURRENT_OFF_A < PZEM_PLASMA_CURRENT_ON_A):
        failures.append(
            "PZEM_PLASMA_CURRENT_OFF_A must be less than PZEM_PLASMA_CURRENT_ON_A (hysteresis)."
        )
    return failures

from drivers.pirani      import PiraniController
from drivers.mfc_control import MFCController
from drivers.turbo_rpm   import TurboRPMController
from drivers.pzem_meter  import PZEMController
from state_machine       import SputterStateMachine, STATE_COLORS
from ui.graph            import ScrollingGraph


# ════════════════════════════════════════════════════════
#  PERSISTENT EVENT LOG
# ════════════════════════════════════════════════════════
# Append-only record of every operator-visible error/warning and every
# state transition -- the GUI status bar only shows the latest message and
# auto-expires it after ERROR_DISPLAY_SECONDS, so this is the only place an
# incident can be reconstructed after the fact.
logging.basicConfig(
    filename=os.path.join(os.path.dirname(os.path.abspath(__file__)), EVENT_LOG_FILENAME),
    level=logging.INFO,
    format="%(asctime)s %(message)s",
)
_event_log = logging.getLogger("sputter_ctrl")

def _log_event(msg):
    """Logging must never crash the control loop."""
    try:
        _event_log.info(msg)
    except Exception:
        pass


# ════════════════════════════════════════════════════════
#  HARDWARE INIT
# ════════════════════════════════════════════════════════
GPIO.setmode(GPIO.BCM)

# Turbo inlet valve (GPIO 4 -> BC547 -> relay, valve on NC contact):
# LOW = relay released = NC shorted = valve CLOSED. Held closed from startup;
# driven HIGH (valve open) only at/below TURBO_VALVE_OPEN_RPM_MAX during VENTING (see _poll).
GPIO.setup(GPIO_TURBO_VALVE_PIN, GPIO.OUT)
GPIO.output(GPIO_TURBO_VALVE_PIN, GPIO.LOW)

i2c = ExtendedI2C(I2C_BUS_NUMBER)
ads = ADS.ADS1115(i2c, address=ADS1115_I2C_ADDRESS)
ads.gain = ADC_GAIN

pirani    = PiraniController(ads)
mfc       = MFCController(ads, i2c=i2c)
turbo_rpm = TurboRPMController(ads)
pzem      = PZEMController()  # optional hardware — see drivers/pzem_meter.py; never blocks startup
sm        = SputterStateMachine()

def _startup_self_test():
    """Runs once, before the poll thread starts. Validates config
    invariants (config_sanity_failures()) and confirms the ADS1115 and
    MCP4725 DAC actually respond on the I2C bus. Refuses to start on
    failure rather than silently running with a broken safety threshold or
    a missing sensor. Console-only -- no GUI exists yet at this point in
    startup, so failures print to stderr/console and exit.
    """
    failures = config_sanity_failures()

    try:
        if i2c.try_lock():
            try:
                addrs = i2c.scan()
            finally:
                i2c.unlock()
        else:
            addrs = []
            failures.append("Could not lock I2C bus to scan for devices.")
    except Exception as e:
        addrs = []
        failures.append(f"I2C scan failed: {e}")

    if ADS1115_I2C_ADDRESS not in addrs:
        failures.append(f"ADS1115 not detected on I2C bus at 0x{ADS1115_I2C_ADDRESS:02X}.")
    if ARGON_DAC_I2C_ADDRESS not in addrs:
        failures.append(f"MCP4725 DAC not detected on I2C bus at 0x{ARGON_DAC_I2C_ADDRESS:02X}.")

    if failures:
        msg = "Startup self-test FAILED:\n  - " + "\n  - ".join(failures)
        print(msg, file=sys.stderr)
        _log_event("STARTUP SELF-TEST FAILED: " + "; ".join(failures))
        sys.exit(1)

    _log_event("Startup self-test passed.")


_startup_self_test()
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

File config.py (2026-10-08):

# config.py — Centralized configuration for Sputter Controller

# ════════════════════════════════════════════════════════
#  GPIO PINS (BCM numbering)
# ════════════════════════════════════════════════════════
GPIO_PIRANI_PIN           = 17   # Input from Pirani gauge / control line for opto logic
GPIO_MFC_VALVE_CLOSE_PIN  = 27   # MFC valve close (emergency shut)
GPIO_TURBO_VALVE_PIN      = 22   # Turbo inlet valve relay (BC547 driver, valve on NC
                                 # contact): GPIO HIGH = valve OPEN, LOW = valve CLOSED.
                                 # Held closed at all times; opened only at/below
                                 # TURBO_VALVE_OPEN_RPM_MAX during VENTING.
                                 # Physical pin 15.
TURBO_VALVE_OPEN_RPM_MAX  = 35000  # During VENTING, open the turbo inlet valve once
                                 # turbo pump RPM (tach on ADC A2) drops to or below this
                                 # speed (latched until the state machine leaves VENTING).
                                 # Replaces the earlier pressure-based (mbar) trigger —
                                 # RPM reflects rotor state directly instead of inferring
                                 # it from chamber pressure.
TURBO_VALVE_CONFIRM_SAMPLES = 3  # Consecutive polling reads at/below TURBO_VALVE_OPEN_RPM_MAX
                                 # required before the valve opens (3 × 0.2 s poll = 0.6 s).
                                 # A corrupted read on the software I2C bus (EMI bit-flips
                                 # return garbage without raising) must never open the valve.
VENTING_PUMP_OFF_PROMPT_RPM = 2000  # During VENTING, once turbo RPM drops to/below
                                 # this, the GUI prompts the operator to turn off the
                                 # primary/roughing pump (main.py's _refresh()). Separate
                                 # from TURBO_RPM_STALL_THRESHOLD -- this is an operator
                                 # cue during a normal vent, not a fault threshold.

# ════════════════════════════════════════════════════════
#  I2C BUS
# ════════════════════════════════════════════════════════
I2C_BUS_NUMBER = 1   # hardware I2C on GPIO2/3 (physical pins 3/5),
                     # enabled via dtparam=i2c_arm=on in /boot/firmware/config.txt

# ════════════════════════════════════════════════════════
#  ADC CONFIGURATION
# ════════════════════════════════════════════════════════
ADC_VREF  = 3.33      # Reference voltage (volts)
ADC_GAIN  = 1         # ADS1115 gain setting

# ADC Channel Assignment
ADC_CHANNEL_PIRANI    = 0   # Pirani gauge on A0
ADC_CHANNEL_MFC       = 1   # MFC flow on A1
ADC_CHANNEL_TURBO_RPM = 2   # Turbo pump RPM tach output on A2

# ════════════════════════════════════════════════════════
#  TURBO PUMP RPM (tach output on ADC A2)
# ════════════════════════════════════════════════════════
TURBO_RPM_VOLTAGE_FULL_SCALE = 3.3      # Volts at A2 for full-scale RPM
TURBO_RPM_FULL_SCALE         = 90000.0  # RPM at TURBO_RPM_VOLTAGE_FULL_SCALE

# ════════════════════════════════════════════════════════
#  MFC CONTROLLER PARAMETERS
# ════════════════════════════════════════════════════════
MFC_FULL_SCALE = 700.0    # Full-scale flow in sccm (MKS 1179A Ar: 0–5V setpoint = 0–700 sccm)
MFC_SETPOINT_VOLTAGE_FULL_SCALE = 5.0  # Volts at the MFC's analog setpoint pin for full-scale flow
MFC_GAS_CORRECTION_FACTOR = 1.39  # For Argon

# ════════════════════════════════════════════════════════
#  TURBO PUMP OPTO THRESHOLDS (ADC values)
# ════════════════════════════════════════════════════════
TURBOOPTO_ON_THRESHOLD  = 10500   # ADC ≤ this: vacuum safe → turbo opto ON
TURBOOPTO_OFF_THRESHOLD = 15000   # ADC ≥ this: vacuum unsafe → turbo opto OFF
                                  # (must be > ON_THRESHOLD)
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

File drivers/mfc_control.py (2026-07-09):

import time

import RPi.GPIO as GPIO
from adafruit_ads1x15.analog_in import AnalogIn
from config import (
    ADC_VREF,
    MFC_FULL_SCALE,
    MFC_SETPOINT_VOLTAGE_FULL_SCALE,
    MFC_GAS_CORRECTION_FACTOR,
    ADC_CHANNEL_MFC,
    GPIO_MFC_VALVE_CLOSE_PIN,
    ARGON_DAC_I2C_ADDRESS,
    ARGON_DAC_VREF,
    ARGON_DAC_RESOLUTION,
    PRESSURE_CONTROL_KP,
    PRESSURE_CONTROL_KD,
    PRESSURE_CONTROL_KI,
    PRESSURE_CONTROL_ICLAMP,
)


class MFCController:

    def __init__(self, ads, i2c=None):
        self.valve_close_pin = GPIO_MFC_VALVE_CLOSE_PIN
        self.valve_closed = False
        self.flow_target = 0.0
        self.i2c = i2c
        self.dac_address = ARGON_DAC_I2C_ADDRESS

        # ADC channel A1
        self.channel = AnalogIn(ads, ADC_CHANNEL_MFC)

        # Initialize valve close pin (default: released)
        GPIO.setup(self.valve_close_pin, GPIO.IN)

        # Configure the DAC if we have an I2C bus.
        self.dac_ready = False

        self.dac_voltage = 0.0
        self.dac_code = 0

        # PID controller state
        self._prev_error = None
        self._prev_time  = None
        self._integral   = 0.0
        if self.i2c is not None:
            i2c_locked = False
            try:
                i2c_locked = self.i2c.try_lock()
                if i2c_locked:
                    addrs = self.i2c.scan()
                    self.dac_ready = self.dac_address in addrs
            except Exception:
                self.dac_ready = False
            finally:
                if i2c_locked:
                    try:
                        self.i2c.unlock()
                    except Exception:
                        pass

    def set_flow(self, sccm):
        """Set the argon MFC flow target via the DAC.

        The MFC wants 0–5V for 0–MFC_FULL_SCALE sccm. An op-amp stage
        level-shifts the DAC output up to that full range (ARGON_DAC_VREF
        reflects this), so the clamp below is just a safety ceiling at the
        DAC's actual max, not a routine cap on commanded flow.
        """
        self.flow_target = max(0.0, min(float(sccm), MFC_FULL_SCALE))

        if not self.dac_ready or self.i2c is None:
            return

        required_voltage = (self.flow_target / MFC_FULL_SCALE) * MFC_SETPOINT_VOLTAGE_FULL_SCALE
        dac_voltage = min(required_voltage, ARGON_DAC_VREF)
        code = int((dac_voltage / ARGON_DAC_VREF) * (ARGON_DAC_RESOLUTION - 1))
        code = max(0, min(code, ARGON_DAC_RESOLUTION - 1))
        self.dac_voltage = dac_voltage
        self.dac_code = code
        self._write_dac(code)

    def _write_dac(self, code):
        """Write a 12-bit code to the MCP4725 using a retrying lock mechanism."""
        if self.i2c is None:
            return

        # Prepare standard MCP4725 fast-write command bytes
        # [0b01000000 (write DAC register), high_byte, low_byte]
        high_byte = (code >> 4) & 0xFF
        low_byte = (code << 4) & 0xFF
        data = bytes([0x40, high_byte, low_byte])

        # Retry loop to guarantee delivery instead of dropping the write
        timeout = 0.1  # 100 milliseconds max wait time
        start = time.time()
        i2c_locked = False
        
        while time.time() - start < timeout:
            if self.i2c.try_lock():
                i2c_locked = True
                break
            time.sleep(0.002) # Yield briefly before re-trying

        if not i2c_locked:
            print("[WARN] DAC write dropped: I2C bus stayed busy too long.")
            return

        try:
            self.i2c.writeto(self.dac_address, data)
        except Exception as e:
            print(f"[ERROR] Physical DAC I2C transaction failed: {e}")
        finally:
            self.i2c.unlock()

    def read(self):
        """Read sensor and return calculated flow. Returns a result dict."""
        adc     = self.channel.value
        voltage = self.channel.voltage
        flow    = (voltage / ADC_VREF) * MFC_FULL_SCALE * MFC_GAS_CORRECTION_FACTOR

        return {
            "adc": adc,
            "voltage": voltage,
            "flow": flow,
            "valve_closed": self.valve_closed,
            "dac_ready": self.dac_ready,
            "flow_target": self.flow_target,
            "dac_voltage": self.dac_voltage,
            "dac_code": self.dac_code,
        }


    def valve_close(self):
        """
        Force valve closed by pulling MFC valve close pin LOW.
        This is an emergency closure mechanism.
        Also clears PID state to avoid spikes on re-arm.
        """
        GPIO.setup(self.valve_close_pin, GPIO.OUT)
        GPIO.output(self.valve_close_pin, GPIO.LOW)
        self.valve_closed = True
        self.set_flow(0.0)
        self._prev_error = None
        self._prev_time  = None
        self._integral   = 0.0

    def valve_release(self):
        """
        Release valve-close override by setting pin to INPUT.
        MFC resumes normal setpoint control from upstream controller.
        """
        GPIO.setup(self.valve_close_pin, GPIO.IN)
        self.valve_closed = False

    def pressure_control_step(self, current_voltage, target_voltage):
        """PID control step: nudge MFC flow to drive Pirani toward target_voltage.

        Higher voltage = higher pressure.
        error > 0 -> above target -> reduce flow
        error < 0 -> below target -> increase flow
        Called once per poll tick from the polling thread.
        """
        now   = time.time()
        error = current_voltage - target_voltage

        if self._prev_error is not None and self._prev_time is not None:
            dt = now - self._prev_time
            if dt > 0:
                d_term = PRESSURE_CONTROL_KD * (error - self._prev_error) / dt
                self._integral += error * dt
                # Anti-windup: clamp so the I contribution never exceeds ICLAMP sccm.
                # Guard against KI == 0 (e.g. while tuning) — no clamp needed then,
                # since the I term is zero anyway.
                if PRESSURE_CONTROL_KI > 0:
                    limit = PRESSURE_CONTROL_ICLAMP / PRESSURE_CONTROL_KI
                    self._integral = max(-limit, min(self._integral, limit))
            else:
                d_term = 0.0
        else:
            d_term = 0.0
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

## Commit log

2026-06-13 Add config.py and refactor sputter workflow with argon flush and plasma stages
    - added centralized config.py for ADC/DAC addresses, thresholds, and GUI settings
    - added ARGON_FLUSH, PLASMA_IGNITING, and SPUTTER_READY workflow states
    - restored Start Sputter button while keeping argon flush separate
    - introduced placeholder plasma UI pane and _ignite_plasma() stub
    - added MFC DAC/flow placeholders and argon flush pressure handling
    - updated state/button logic and status messaging for new stages
2026-06-18 added mfc flow rate and dac output graphs overlapping
2026-06-20 added proportional control for pressure using the actuation of mfc
2026-06-25 sputter pressure target input, pirani cal table interpolation, venting at 2.5V, clean shutdown
2026-06-25 PID control, log-linear pirani interpolation, sputter pressure input, clean shutdown, UI fixes
    [config.py, main.py, mfc_control.py]
2026-07-03 I2C on software bus 3 (GPIO23/24), turbo valve on GPIO22 relay, pirani mbar display, safety fixes
    [adc_test.py, config.py, dac_test.py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]
2026-07-07 Debounce turbo valve open decision: require consecutive above-limit reads
    The T-valve latched open on a single ADC sample above 0.01 mbar during
    VENTING. On the bit-banged I2C bus an EMI-corrupted read can silently
    return garbage (no CRC on ADS1115), so one bad sample opened the valve
    at high vacuum and the anti-chatter latch held it open for the whole
    vent. The valve now opens only after TURBO_VALVE_CONFIRM_SAMPLES (3)
    consecutive reads above the threshold; a below-limit read resets the
    count, and leaving VENTING (incl. E-STOP) clears it so a partial count
    can't carry into the next vent.
    Decision logic extracted as pure turbo_valve_step() in the test-
    extractable region of main.py; 10 new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
    [config.py, fakes.py, main.py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]
2026-07-07 Raise turbo valve pressure cap to 1 mbar; add turbo RPM display on ADC A2
    TURBO_VALVE_OPEN_MBAR: 0.01 -> 1.0 mbar. Valve actuation logic itself
    (turbo_valve_step, debounced latch) is unchanged.
    Add TurboRPMController (turbo_rpm.py): reads the turbo pump tach output
    on ADC channel A2 (0-3.3V linear -> 0-90000 RPM, clamped) and displays
    it in the Pirani panel as "T-RPM". Read every poll tick regardless of
    state. Display only for now -- not yet wired into valve actuation.
2026-07-07 Switch turbo inlet valve interlock from pressure to RPM (ADC A2)
    turbo_valve_step() now gates on turbo pump RPM (tach on ADC A2, via
    TurboRPMController) instead of chamber pressure: opens once RPM sustains
    TURBO_VALVE_CONFIRM_SAMPLES consecutive reads at/below
    TURBO_VALVE_OPEN_RPM_MAX (20000), same debounce/latch/reset-on-E-STOP
    behavior as before. Removes the now-unused TURBO_VALVE_OPEN_MBAR gate.
    Also fixes a latent bug: TURBO_VALVE_CONFIRM_SAMPLES was referenced in
    turbo_valve_step() but never imported in main.py, so the real GUI would
    have hit NameError the first time a vent crossed the valve threshold.
    GUI: T-RPM and T-RPM voltage moved to the right edge of the Pirani
    panel. Tests and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
    [config.py, fakes.py, main.py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]
2026-07-07 Add Raspi HAT design + Pirani datasheet, ignore transcript exports
    Publishes the custom Raspberry Pi HAT (schematic/PCB/BOM) and moves the
    Pirani datasheet into Docs/, closing the gap between "repo is public" and
    "BOM/schematics are actually in it". Also adds a .gitignore rule for
    conversation transcript exports (pattern already used in 4rynv.github.io)
    so session transcripts don't end up in a public repo by accident.
    [Raspi_HAT.kicad_pcb, Raspi_HAT.kicad_sch]
2026-07-09 Add PZEM-004T plasma detection, vent-completion safety gate, simulation mode
    Adds energy-meter-based plasma sensing with cross-sensor checks, closes a
    safety gap where venting could complete before the primary pump was off,
    and adds a hardware-free SPUTTER_SIM mode for testing without the rig.
2026-07-27 Add web dashboard (SSE + stdlib server), mac launchers, app icons
    [Raspi_HAT.kicad_pcb]
2026-07-29 Restructure into drivers/ui/sim/hardware/assets/scripts; rebrand to VacDepoctrl
    [Raspi_HAT.kicad_pcb, Raspi_HAT.kicad_sch]
2026-10-08 Fix Pi 5 deployment and hardware I2C; document agent access
    [adc_test.py, config.py, dac_test.py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]
2026-10-08 Document Pi 5 header pinout and shared hardware I2C wiring
